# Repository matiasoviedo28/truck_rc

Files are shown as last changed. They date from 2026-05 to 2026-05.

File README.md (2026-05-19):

# RC Truck NeutronLab — ESP32 Control System

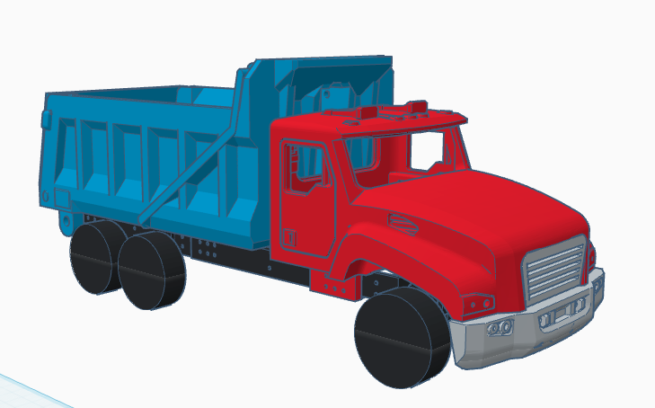
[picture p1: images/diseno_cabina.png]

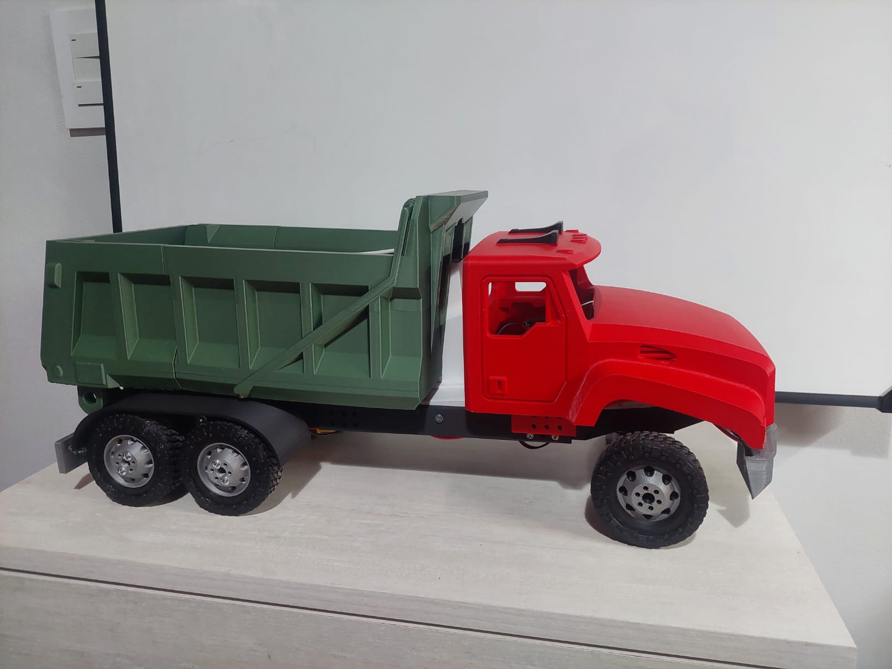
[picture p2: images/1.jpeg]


Sistema de control inalámbrico para camión RC con tolva volcadora basado en ESP32, con interfaz web embebida accesible desde cualquier celular sin necesidad de aplicación.

El proyecto reemplaza los radiocontroles tradicionales por un control vía WiFi (modo Access Point) servido directamente desde el ESP32, replicando el comportamiento de un camión real: cardán/toma de fuerza, bloqueos cruzados de seguridad, luces de freno con timer, balizas, indicadores de giro automáticos y failsafe por pérdida de conexión.

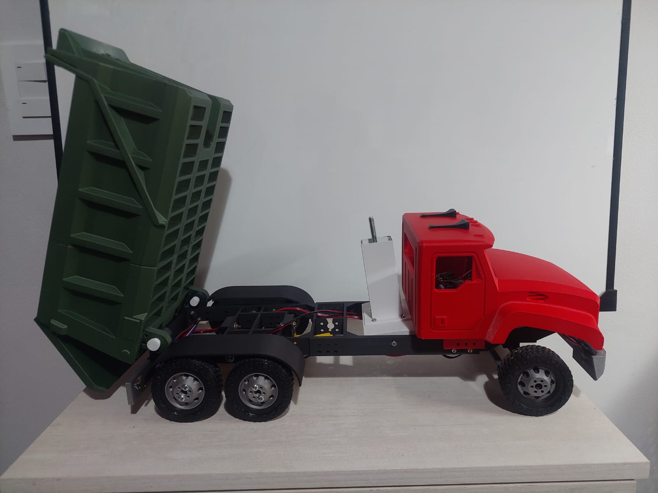
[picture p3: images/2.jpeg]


---

## Tabla de contenidos

- [Características principales](#características-principales)
- [Hardware utilizado](#hardware-utilizado)
- [Documentación](#documentación)
- [Estructura del proyecto](#estructura-del-proyecto)
- [Contribuciones](#contribuciones)
- [Licencia](#licencia)
- [Créditos](#créditos)

---

## Características principales

- **Control vía WiFi sin internet** — el ESP32 crea su propio Access Point, no requiere router externo.
- **Interfaz web embebida** — funciona en cualquier celular con navegador, sin instalar apps.
- **Volante táctil SVG** — control de dirección con gestos de rotación realistas.
- **Tolva con motor paso a paso** — controlada directamente desde el ESP32 con AccelStepper.
- **Cardán virtual** — simula la toma de fuerza de un camión real con bloqueos cruzados.
- **Sistema de luces realista** — bajas, freno con timer, reversa, giros automáticos y balizas.
- **Failsafe automático** — corta motores ante pérdida de conexión.
- **Indicador ONLINE/OFFLINE** en tiempo real.

---

## Hardware utilizado

| Componente | Modelo / Especificación |
|---|---|
| Microcontrolador | ESP32 DevKit V1 (30 pines) |
| Driver paso a paso | A4988 (con disipador) |
| Motor de tolva | NEMA17 |
| Motor de tracción | DC con driver PWM (puente H) |
| Servo de dirección | SG90 / MG90S (50 Hz, 500-2400 µs) |
| Alimentación motor | 12V (batería o fuente) |
| Alimentación lógica | 5V (del ESP32 o externa) |
| LEDs | Luces bajas, freno, reversa, giros izq/der |

---

## Documentación

| Archivo | Contenido |
|---|---|
| [`guia_armado.md`](guia_armado.md) | Paso a paso completo: impresión 3D, ensamble mecánico y eléctrico |
| [`conexiones.md`](conexiones.md) | Diagrama de conexiones, tabla de pines ESP32 y configuración del A4988 |
| [`interfaz_web.md`](interfaz_web.md) | Control WiFi, protocolo HTTP e interfaz visual |
| [`funciones.md`](funciones.md) | Funciones del camión y sistema de seguridad / failsafe |
| [`instalacion.md`](instalacion.md) | Requisitos, librerías y carga del firmware |

---

## Estructura del proyecto

```
.
├── truck_rc_neutronlab.ino   # Sketch principal del ESP32
├── README.md                 # Este archivo
├── guia_armado.md            # Paso a paso de construcción
├── conexiones.md             # Pines y diagrama eléctrico
├── interfaz_web.md           # Control WiFi e interfaz
├── funciones.md              # Funciones y failsafe
├── instalacion.md            # Carga del firmware
├── images/                   # Imágenes del proyecto
└── stl/                      # Archivos para impresión 3D
```

---

## Contribuciones

Las contribuciones son bienvenidas. Si querés agregar funcionalidades, corregir bugs o adaptar el proyecto a otros chasis, hacé un fork y mandá un pull request.

Ideas pendientes de implementación:
- Control de velocidad gradual (actualmente PWM fijo en 255).
- Conversión a WebSockets para reducir latencia.
- Modo de "pausa" para el truck con configuración persistente.
- Telemetría de batería.

---

## Licencia

Este proyecto está bajo licencia MIT — libre uso, modificación y distribución.

---

## Créditos

**Proyecto creado por:** Matías Oviedo
**Nick:** NeutronLab
**Contacto:** matiasalbertooviedogonzalez@gmail.com

---

> Si te sirvió el proyecto o te gustó la idea, no olvides dejar una estrella en el repositorio.

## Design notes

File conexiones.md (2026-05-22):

# Diagrama de conexiones y pines

## Diagrama general

```
                        ┌─────────────────┐
                        │   CELULAR       │
                        │   (Navegador)   │
                        └────────┬────────┘
                                 │ WiFi 2.4 GHz
                                 │ (AP del ESP32)
                                 │
                        ┌────────▼────────┐
                        │     ESP32       │
                        │   (Servidor     │
                        │     web AP)     │
                        └────────┬────────┘
                                 │
        ┌────────────┬───────────┼───────────┬──────────────┐
        │            │           │           │              │
   ┌────▼────┐  ┌────▼────┐ ┌────▼────┐ ┌────▼────┐  ┌──────▼──────┐
   │  Servo  │  │ Driver  │ │ Driver  │ │  LEDs   │  │   Driver    │
   │ Dirección│ │ Motor DC│ │  A4988  │ │ (luces) │  │   A4988     │
   │         │  │ (PWM)   │ │ NEMA17  │ │         │  │             │
   └─────────┘  └─────────┘ └─────────┘ └─────────┘  └─────────────┘
```

---

## Tabla de pines del ESP32

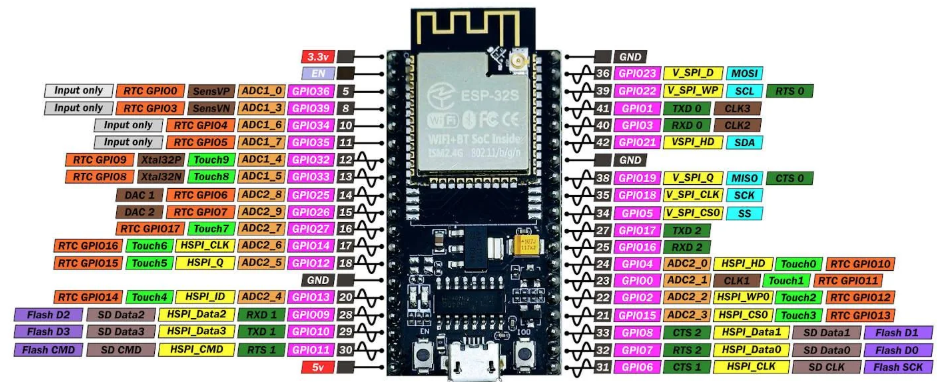
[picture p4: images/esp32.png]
ESP32


| GPIO | Función | Descripción |
|---|---|---|
| **2** | Servo dirección | PWM 50 Hz al servo (rango 500-2400 µs) |
| **4** | DIR (A4988) | Dirección del motor paso a paso de tolva |
| **12** | Motor A | PWM hacia adelante (motor de tracción) |
| **13** | Motor B | PWM hacia atrás / reversa |
| **14** | Luces bajas | Salida digital LED bajas |
| **25** | Giro izquierdo | Salida digital LED giro izq |
| **26** | Luz reversa | Salida digital LED reversa |
| **27** | Luz freno | Salida digital LED freno (timer 1500 ms) |
| **32** | STEP (A4988) | Pulsos al motor paso a paso de tolva |
| **33** | Giro derecho | Salida digital LED giro der |
| **5** | ENABLE (A4988) | Habilitación del driver — LOW = activo, HIGH = desactivado |

---

## Conexión del driver A4988

| Pin A4988 | Conectar a | Observación |
|---|---|---|
| VMOT | +12V | Alimentación del motor |
| GND (motor) | GND batería 12V | |
| VDD | +5V | Alimentación de lógica del driver |
| GND (lógica) | GND del ESP32 | **Crítico:** debe compartir GND con ESP32 |
| STEP | GPIO 32 | Pulsos de paso |
| DIR | GPIO 4 | Sentido de giro |
| ENABLE | GPIO 5 | Controlado por software — no conectar a GND |
| RESET | SLEEP | Puenteados entre sí |
| 1A, 1B, 2A, 2B | Bobinas NEMA17 | Identificar con multímetro en continuidad |

> ⚠️ **Importante:** Calibrar el **Vref** del A4988 antes de usarlo. Para NEMA17 típico (1.5A) debe estar entre 0.6V y 0.8V. Medir entre el potenciómetro y GND con el driver alimentado pero **sin el motor conectado**.

> ⚠️ **Nunca conectar o desconectar el motor con el driver alimentado** — destruye instantáneamente el A4988.

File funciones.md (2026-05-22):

# Funciones del camión y sistema de seguridad

## Funciones del camión

### Dirección

- Volante táctil con rotación de hasta ±360° (dos vueltas completas a cada lado).
- Mapeo proporcional al servo físico (rango 55° a 135°, centro en 95°).
- Vuelve al centro automáticamente al soltar.

### Tracción

- **Modo RÁPIDO:** un toque al acelerador y el truck queda avanzando hasta tocar FRENO.
- **Modo LENTO:** mantener presionado para avanzar, soltar para detener.
- Reversa con la misma lógica según modo.

### Tolva volcadora

- Motor NEMA17 controlado con AccelStepper (no bloqueante).
- Recorrido seguro: **9000 pasos** (con margen del límite físico real de 10000).
- Velocidad: 1000 pasos/s, aceleración 400 pasos/s².
- Botón se ilumina durante el movimiento y se apaga al terminar.
- Comportamiento "un toque": va sola hasta el tope, sin STOP intermedio.
- Posición de reposo al encender: **tolva abajo = 0 pasos**. Subir avanza hacia `PASOS_MAXIMOS`, bajar regresa a `0`.

#### Gestión de energía del driver (pin ENABLE)

El driver A4988 se controla mediante el pin **GPIO 5** (ENABLE), evitando que el motor consuma corriente innecesariamente cuando está quieto.

| Momento | Estado ENABLE | Efecto |
|---|---|---|
| Arranque del sistema | HIGH (inactivo) | Motor frío, sin consumo |
| Se recibe comando UP/DOWN | LOW (activo) + delay 2 ms | Driver despierta antes del primer pulso |
| Tolva llega al destino | HIGH (inactivo) | Corriente cortada al terminar |
| Failsafe por pérdida de WiFi | HIGH (inactivo) | Motor se detiene y se desenergiza |

> **Por qué importa:** un NEMA17 parado pero energizado puede alcanzar 50–70 °C en pocos minutos y drenar la batería continuamente. Con el control de ENABLE el motor solo consume durante el movimiento efectivo.

### Sistema de luces

- **Luces bajas:** toggle manual.
- **Luz de freno:** se enciende automáticamente al transicionar de movimiento a detenido, durante **1500 ms** y se apaga sola.
- **Luz de reversa:** activa mientras el truck va en reversa.
- **Giros automáticos:** parpadean en el lado correspondiente cuando el volante supera ±45°.
- **Balizas (4 intermitentes):** toggle manual, parpadeo a 500 ms.

### Cardán (toma de fuerza simulada)

Replica el comportamiento real de un camión: la tolva solo puede operar con el cardán acoplado.

**Bloqueos cruzados:**
- El cardán solo se puede acoplar/desacoplar con el motor detenido.
- Con el cardán acoplado, el acelerador y reversa quedan bloqueados.
- La tolva solo responde si: cardán acoplado + motor detenido + conexión OK.

---

## Sistema de seguridad y failsafe

El sistema tiene múltiples capas de seguridad pensadas para un control inalámbrico.

### Detección de desconexión

- **Frontend (celular):** detecta OFFLINE si no recibe respuesta del ESP32 en **500 ms**.
- **Backend (ESP32):** activa el failsafe si no recibe comandos del frontend en **1000 ms**.

### Acciones de failsafe

Cuando el ESP32 detecta pérdida de conexión:

| Componente | Acción |
|---|---|
| Motor de tracción | **Apagado inmediato** (PWM a 0) |
| Tolva (paso a paso) | **Detención** con `stepper.stop()` + driver desenergizado (ENABLE = HIGH) |
| Servo de dirección | **Queda quieto** en su última posición |
| Luces bajas | Apagadas |
| Balizas | Mantienen parpadeo (señal visual de vehículo abandonado) |

### Defensa en profundidad

Los bloqueos cruzados (cardán ↔ motor, motor ↔ tolva, cardán ↔ tolva) se validan **tanto en el frontend como en el backend**. Aunque el frontend bloquea visualmente los botones inválidos, el ESP32 también los ignora si llegan por algún glitch o manipulación del request.

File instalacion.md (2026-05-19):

# Instalación del firmware

## Requisitos

- Arduino IDE 1.8+ o 2.x
- Plataforma ESP32 instalada en el IDE ([guía oficial](https://docs.espressif.com/projects/arduino-esp32/en/latest/installing.html))

## Librerías necesarias

Instalar desde el **Library Manager** del IDE:

- **AccelStepper** (Mike McCauley) — control del NEMA17
- **ESP32Servo** — control del servo
- `WiFi.h` y `WebServer.h` — incluidas en la plataforma ESP32

## Pasos

1. Clonar el repositorio:
   ```bash
   git clone https://github.com/TU_USUARIO/rc-truck-neutronlab.git
   ```
2. Abrir el archivo `.ino` con Arduino IDE.
3. Seleccionar la placa: **ESP32 Dev Module**.
4. Conectar el ESP32 por USB y elegir el puerto correspondiente.
5. Compilar y subir.
6. Abrir el Serial Monitor a **115200 baudios** para ver la IP del AP al iniciar.

## Prueba inicial recomendada

Antes de conectar todo el hardware, sugiero probar en este orden:

1. ✅ Subir el sketch al ESP32 sin nada conectado.
2. ✅ Conectarse al WiFi `Camion-RC-NeutronLab` desde el celular.
3. ✅ Acceder a `192.168.4.1` y verificar que la interfaz cargue.
4. ✅ Conectar el servo y las luces.
5. ✅ Conectar el motor de tracción.
6. ✅ **Último paso:** conectar el driver A4988 + NEMA17 (con Vref ya calibrado).

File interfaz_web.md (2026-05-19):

# Control WiFi e interfaz web

## Arquitectura

El ESP32 funciona como **Access Point WiFi independiente**. No se conecta a ninguna red externa: crea su propia red a la que el celular se conecta directamente. Esto significa:

- ✅ Funciona en cualquier lugar sin necesidad de WiFi externo
- ✅ Latencia mínima (sin pasar por router)
- ✅ Sin dependencia de internet
- ❌ El celular no tendrá acceso a internet mientras esté conectado al truck

---

## Conexión desde el celular

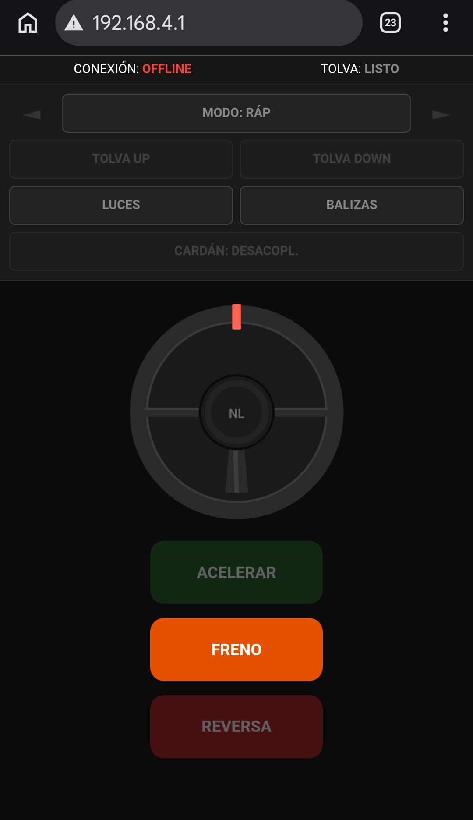
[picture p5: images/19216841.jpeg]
Conexión WiFi


1. **Red WiFi:** `Camion-RC-NeutronLab`
2. **Contraseña:** `12345678`
3. **Abrir navegador en:** `http://192.168.4.1`

Ambos valores se pueden modificar al inicio del sketch:

```cpp
const char* ssid     = "Camion-RC-NeutronLab";
const char* password = "12345678";
```

---

## Protocolo de comunicación

El frontend hace **polling HTTP cada 100 ms** al endpoint `/c` con los siguientes parámetros:

| Parámetro | Tipo | Valores | Descripción |
|---|---|---|---|
| `m` | int | 0, 1, 2 | Estado del motor: 0=stop, 1=adelante, 2=reversa |
| `d` | int | -360 a 360 | Ángulo del volante virtual |
| `l` | int | 0, 1 | Luces bajas |
| `h` | int | 0, 1 | Balizas (4 intermitentes) |
| `c` | int | 0, 1 | Cardán acoplado |
| `t` | char | U, D, espacio | Comando de tolva: Up, Down, sin acción |

**Ejemplo de request:**
```
GET /c?m=1&d=45&l=1&h=0&c=0&t=U
```

**Respuesta del ESP32:** estado actual de la tolva (`LISTO`, `SUBIENDO` o `BAJANDO`) en texto plano.

---

## Interfaz visual

La interfaz está optimizada para uso vertical en celulares y cuenta con:

- **Header con chips de estado:** CONEXIÓN (ONLINE/OFFLINE) y TOLVA (estado actual).
- **Indicadores de giro:** flechas ◄ ► que parpadean en naranja según ángulo del volante o si las balizas están activas.
- **Volante SVG estilo camión clásico** con marcador rojo central y 3 rayos.
- **Triggers verticales:** ACELERAR (verde), FRENO (naranja), REVERSA (rojo).
- **Controles de tolva:** TOLVA UP / TOLVA DOWN con bloqueos automáticos.
- **Botón CARDÁN** con feedback de estado (ACOPLADO / DESACOPL.).
- **Modo de manejo:** RÁPIDO (toque y mantiene) o LENTO (mantener presionado).

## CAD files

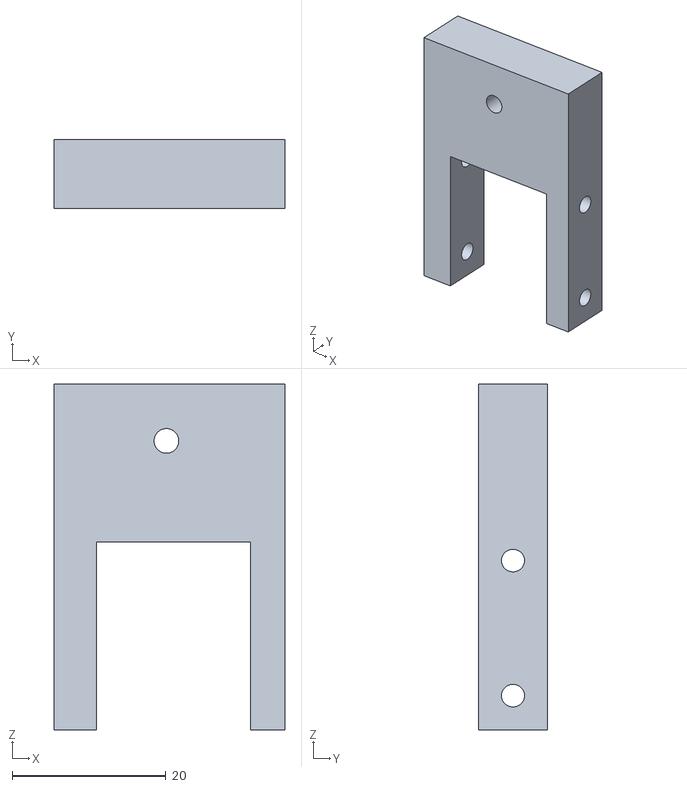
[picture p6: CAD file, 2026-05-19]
stl/SUPORT_MOTOR.stl
30.0 x 9.00 x 45.0

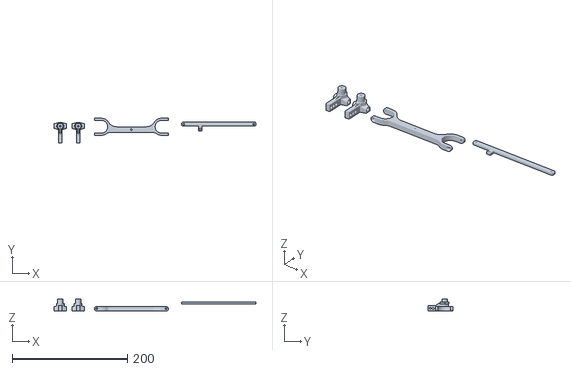
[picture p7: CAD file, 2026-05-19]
stl/DIRECCION_ARTICULADA.stl
350.1 x 42.9 x 21.0

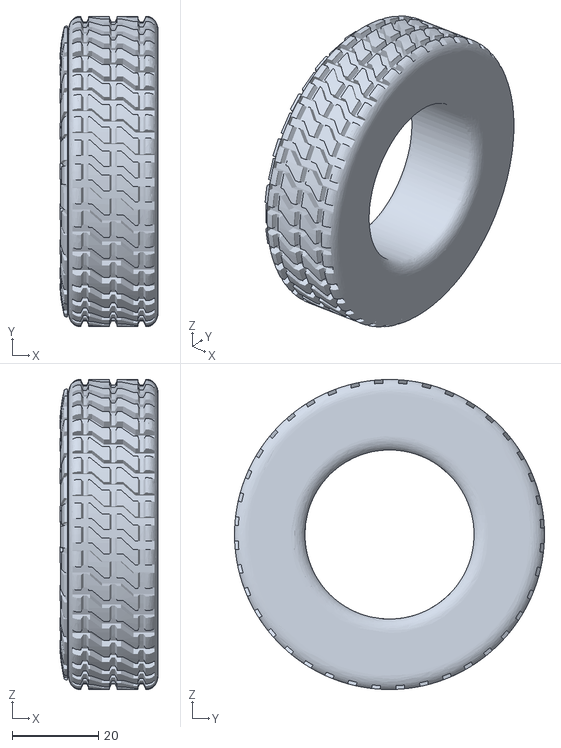
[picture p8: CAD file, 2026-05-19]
stl/NEUMATICO.stl
22.8 x 72.0 x 72.0

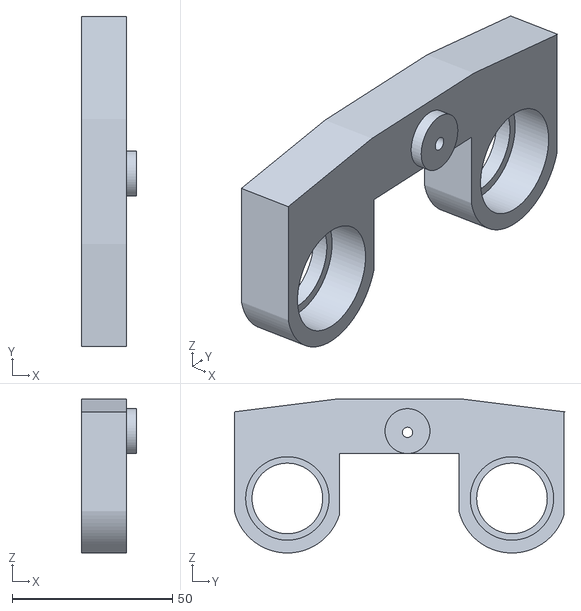
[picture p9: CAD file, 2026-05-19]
stl/MASAS.stl
17.0 x 103.0 x 48.0

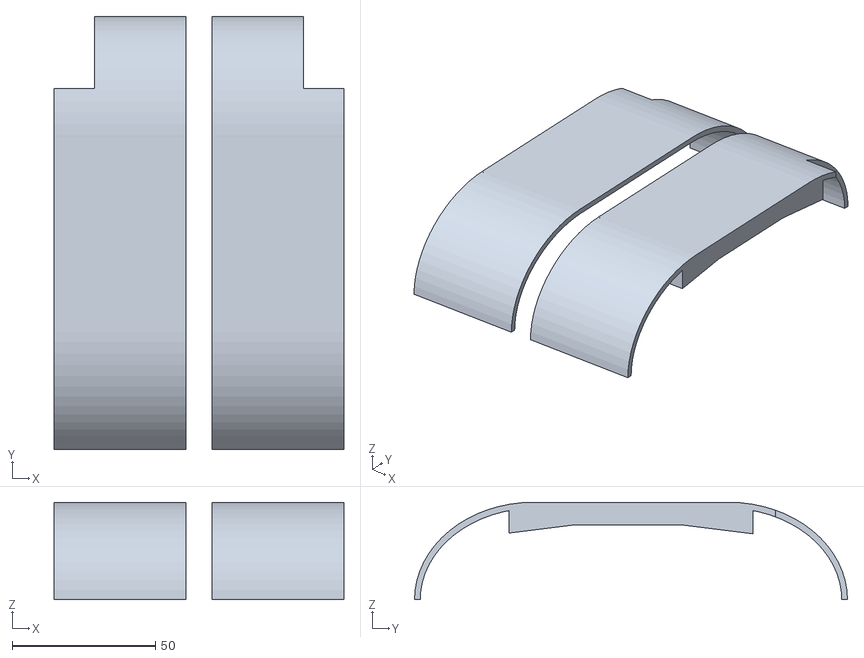
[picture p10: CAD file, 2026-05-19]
stl/GUARDABARROS_TRA.stl
101.0 x 151.0 x 34.0

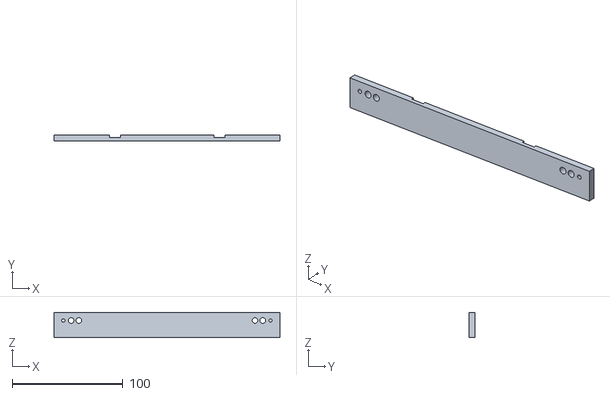
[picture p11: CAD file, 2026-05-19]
stl/PARACHOQUES_TRA.stl
204.0 x 5.00 x 23.0

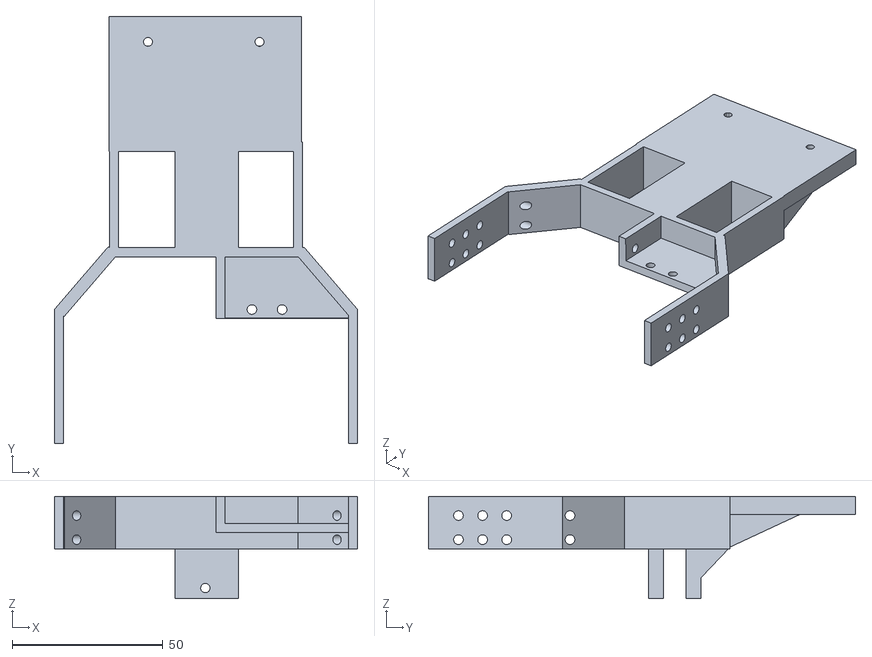
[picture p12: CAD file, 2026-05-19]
stl/CHASIS_1.stl
100.5 x 141.8 x 34.0

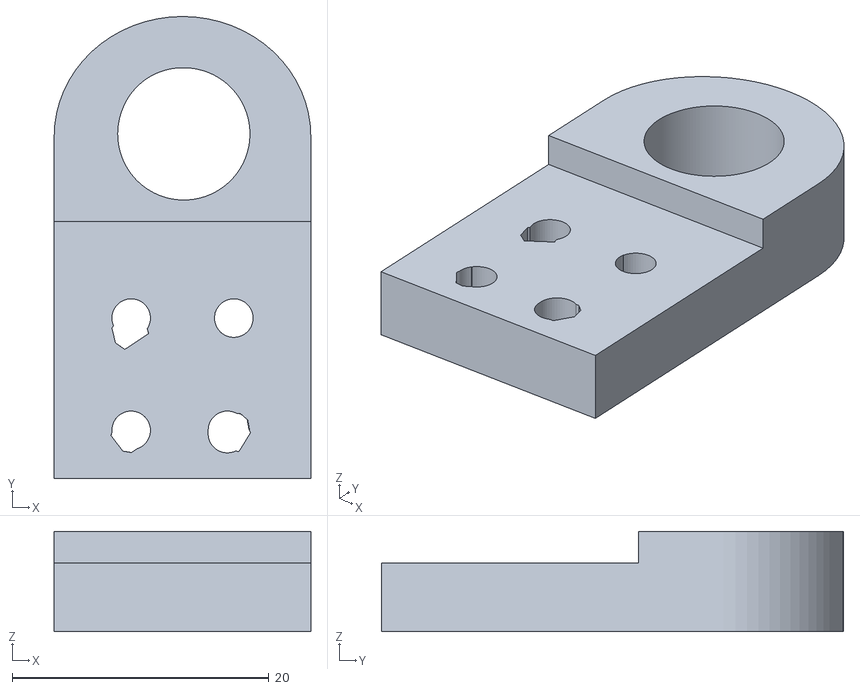
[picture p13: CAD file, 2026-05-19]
stl/BISAGRA_TOLVA.stl
20.0 x 36.0 x 7.80

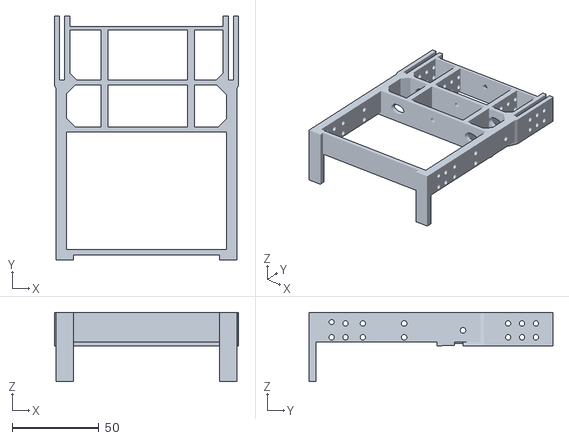
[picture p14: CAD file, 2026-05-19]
stl/CHASIS_3.stl
106.5 x 141.0 x 40.0

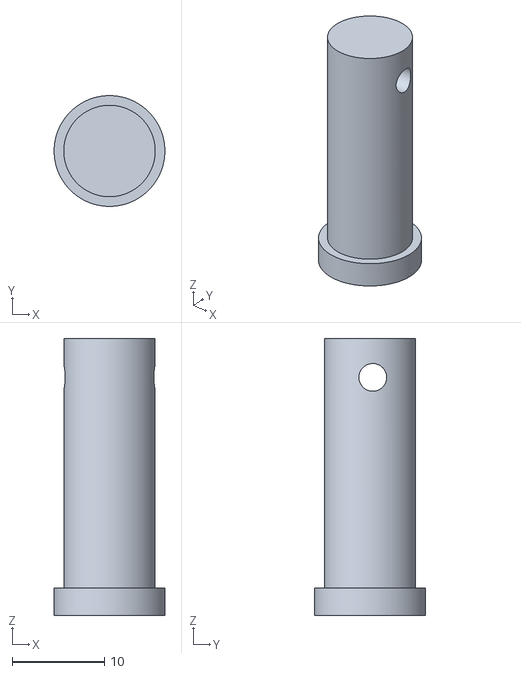
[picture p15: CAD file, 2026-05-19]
stl/PERNO_TOLVA.stl
12.0 x 12.0 x 30.0

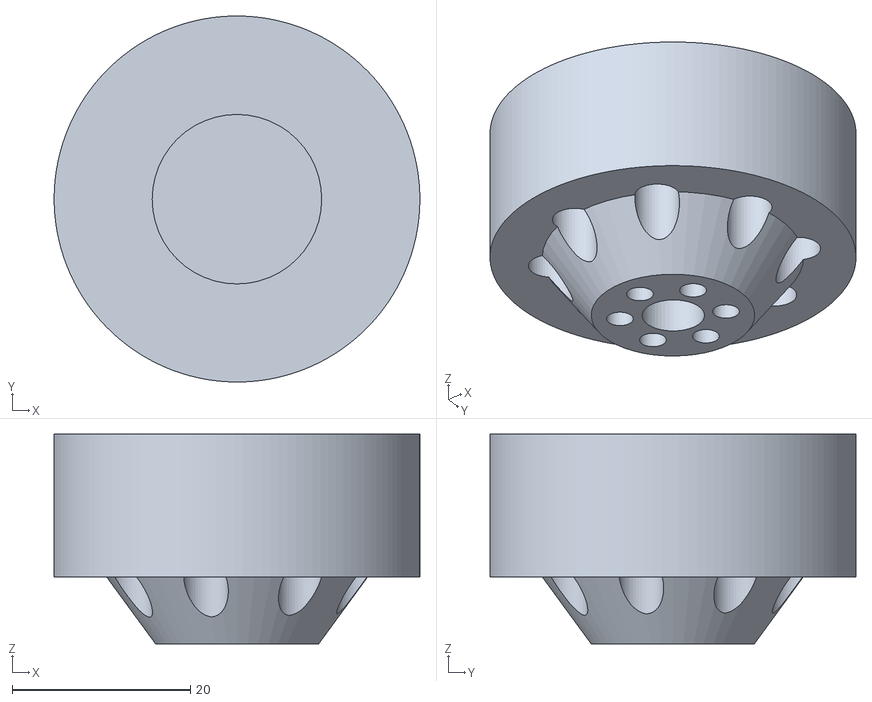
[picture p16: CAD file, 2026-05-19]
stl/LLANTA_DEL.stl
41.0 x 41.0 x 23.5

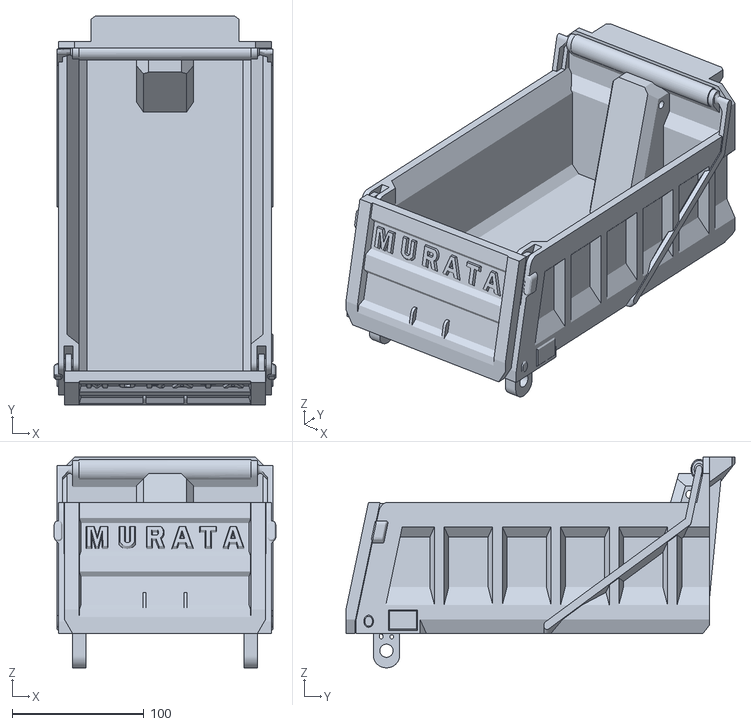
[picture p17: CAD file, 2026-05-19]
stl/CAJA_TOLVA.stl
168.5 x 295.8 x 160.2

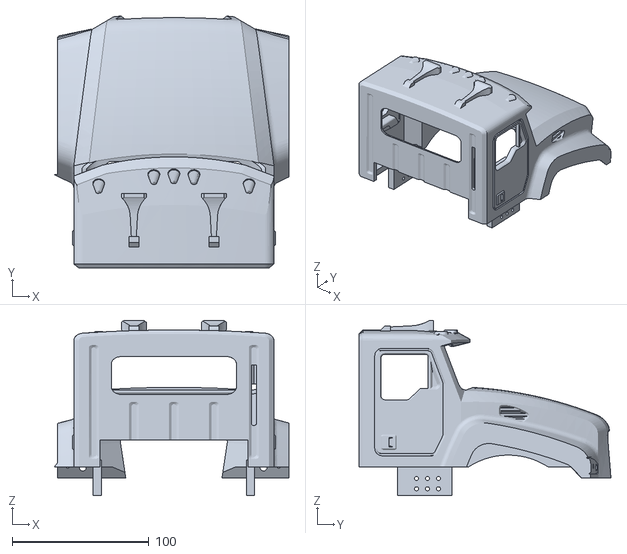
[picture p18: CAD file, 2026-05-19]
stl/CABINA.stl
171.5 x 184.0 x 128.0

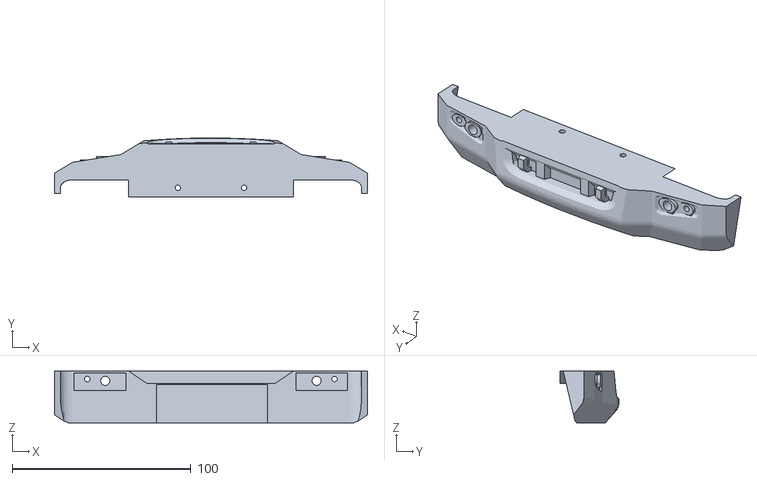
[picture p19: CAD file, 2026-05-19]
stl/PARACHOQUES_DEL.stl
175.0 x 33.0 x 29.0

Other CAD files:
stl/LLANTA_TRA.stl
stl/RADIADOR.stl
stl/EJE.stl
stl/CHASIS_2.stl

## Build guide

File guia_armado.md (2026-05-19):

# Guía de armado — RC Truck NeutronLab

Truck terminado

Esta guía cubre todo el proceso de construcción del camión RC: desde imprimir las piezas hasta la puesta en marcha. Seguí el orden recomendado para evitar tener que desarmar cosas que ya ensamblaste.

---

## Tabla de contenidos

- [Materiales y herramientas necesarias](#materiales-y-herramientas-necesarias)
- [Paso 1 — Impresión 3D](#paso-1--impresión-3d)
- [Paso 2 — Armado del chasis](#paso-2--armado-del-chasis)
- [Paso 3 — Ejes y ruedas](#paso-3--ejes-y-ruedas)
- [Paso 4 — Sistema de dirección](#paso-4--sistema-de-dirección)
- [Paso 5 — Motor de tracción](#paso-5--motor-de-tracción)
- [Paso 6 — Electrónica y cableado](#paso-6--electrónica-y-cableado)
- [Paso 7 — Tolva volcadora](#paso-7--tolva-volcadora)
- [Paso 8 — Carrocería y detalles](#paso-8--carrocería-y-detalles)
- [Paso 9 — Prueba final](#paso-9--prueba-final)

---

## Materiales y herramientas necesarias

### Herramientas

- Impresora 3D (usé Bambu Lab A1)
- Destornillador Phillips y plano
- Llave allen (set métrico)
- Multímetro digital
- Soldador de estaño + estaño
- Termocontraíble o cinta aisladora
- Pinza de punta fina

### Tornillería y extras

> _(completar con los tornillos exactos que uses: M2, M3, etc., largo y cantidad)_

| Ítem | Cantidad |
|---|---|
| Tornillos M3 x 10mm | ___ |
| Tornillos M3 x 20mm | ___ |
| Tornillos M2 x 8mm | ___ |
| Tuercas M3 | ___ |
| Varilla roscada (eje tolva) | ___ |
| Cables dupont / silicona | c/n |

---

## Paso 1 — Impresión 3D

Imprimí todas las piezas antes de empezar el armado. Así tenés todo listo y evitás interrupciones.

### Configuración utilizada

| Parámetro | Valor |
|---|---|
| Impresora | Bambu Lab A1 |
| Boquilla | 0.4 mm |
| Altura de capa | 0.2 mm |
| Paredes | 3–4 (ver tabla) |
| Relleno | 20% |
| Material | PLA o PETG |

### Lista de STLs

| Archivo STL | Cantidad | Paredes | Observaciones |
|---|---|---|---|
| `CHASIS_1.stl` | 1 | 4 | Pieza estructural, imprimí con boca abajo si tiene voladizos |
| `CHASIS_2.stl` | 1 | 4 | |
| `CHASIS_3.stl` | 1 | 4 | |
| `EJE.stl` | ___ | 4 | Pieza de carga, máximo relleno recomendado |
| `MASAS.stl` | ___ | 4 | |
| `LLANTA_DEL.stl` | 2 | 3 | |
| `LLANTA_TRA.stl` | 4 | 3 | |
| `NEUMATICO.stl` | 6 | 3 | Imprimir en TPU si es posible, sino PLA flexible |
| `DIRECCION_ARTICULADA.stl` | 1 | 4 | |
| `SUPORT_MOTOR.stl` | 1 | 4 | |
| `CABINA.stl` | 1 | 3 | Pieza estética |
| `RADIADOR.stl` | 1 | 3 | |
| `PARACHOQUES_DEL.stl` | 1 | 3 | |
| `PARACHOQUES_TRA.stl` | 1 | 3 | |
| `GUARDABARROS_TRA.stl` | 2 | 3 | |
| `CAJA_TOLVA.stl` | 1 | 3–4 | |
| `BISAGRA_TOLVA.stl` | ___ | 4 | |
| `PERNO_TOLVA.stl` | ___ | 4 | |

> **Tip:** Las piezas del chasis conviene imprimirlas primero y verificar que encajan antes de imprimir la carrocería.

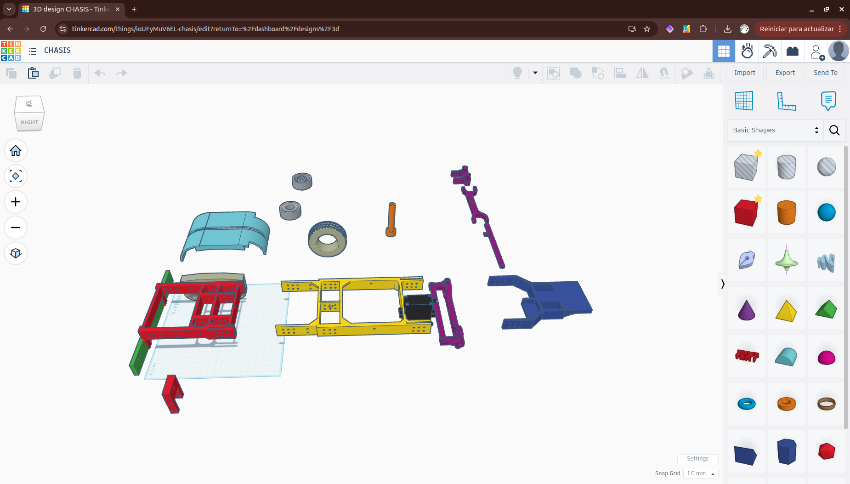
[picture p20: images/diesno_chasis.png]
Diseño del chasis


---

## Paso 2 — Armado del chasis

> 📷 _Foto: chasis armado sin electrónica_

El chasis se divide en 3 partes (`CHASIS_1`, `CHASIS_2`, `CHASIS_3`) que se unen entre sí con tornillos.

**Pasos:**

1. Unir `CHASIS_1` con `CHASIS_2` — alinear los orificios y fijar con tornillos ___(especificar)___.
2. Unir `CHASIS_3` al conjunto anterior.
3. Verificar que el chasis quede rígido y sin flexión lateral.

> _(agregar foto del chasis ensamblado)_

---

## Paso 3 — Ejes y ruedas

> 📷 _Foto: ruedas traseras y eje montados_

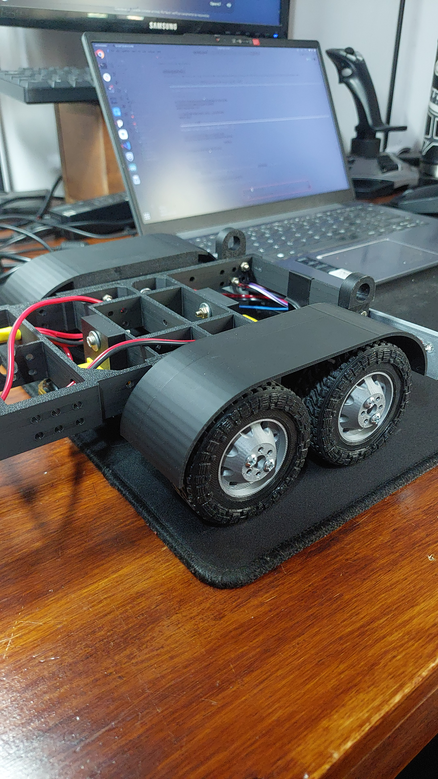
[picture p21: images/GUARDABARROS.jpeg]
Ejes traseros en construcción


**Ensamble de ruedas:**

1. Montar las `MASAS` en el eje.
2. Colocar la `LLANTA_TRA` sobre la masa y fijar con tornillo central.
3. Instalar el `NEUMATICO` sobre la llanta (con un poco de calor si ajusta muy justo en PLA).
4. Repetir para las 4 ruedas traseras y las 2 delanteras (`LLANTA_DEL`).

**Montaje de ejes al chasis:**

1. Insertar el `EJE` en los soportes del chasis.
2. ___(describir cómo queda retenido — tuerca, clip, etc.)___

> _(agregar foto del eje instalado en el chasis)_

---

## Paso 4 — Sistema de dirección

> 📷 _Foto: servo y dirección articulada instalados_

1. Montar la `DIRECCION_ARTICULADA` en el chasis delantero.
2. Insertar el servo SG90/MG90S en su cavidad.
3. Conectar el brazo del servo al mecanismo de dirección.
4. Verificar que el rango de giro no toca topes mecánicos antes de energizar — el código mapea 55° a 135° (centro 95°).

> _(agregar foto del servo instalado)_

---

## Paso 5 — Motor de tracción

> 📷 _Foto: motor DC montado en el soporte_

1. Colocar el motor DC en el `SUPORT_MOTOR`.
2. Fijar el soporte al chasis en la posición ___(especificar)___.
3. Conectar la transmisión al eje trasero ___(describir si hay engranaje, correa, etc.)___.
4. Verificar que el eje gira libre sin fricción excesiva.

> _(agregar foto del motor instalado)_

---

## Paso 6 — Electrónica y cableado

> 📷 _Foto: chasis con toda la electrónica antes de cerrar_

Tolva levantada — electrónica visible

### Componentes a instalar

- ESP32 DevKit V1 (30 pines)
- Driver A4988 + disipador
- Puente H (motor DC)
- LEDs (bajas, freno, reversa, giros)
- Servo SG90/MG90S (ya instalado en paso 4)

### Diagrama de pines

ESP32 conexiones

| GPIO | Función |
|---|---|
| 2 | Servo dirección |
| 4 | DIR (A4988 tolva) |
| 12 | Motor A (adelante) |
| 13 | Motor B (reversa) |
| 14 | Luces bajas |
| 25 | Giro izquierdo |
| 26 | Luz reversa |
| 27 | Luz freno |
| 32 | STEP (A4988 tolva) |
| 33 | Giro derecho |

### Calibración del A4988 (Vref)

> ⚠️ **Hacer esto antes de conectar el NEMA17.**

1. Alimentar el driver (12V en VMOT, 5V en VDD) **sin el motor conectado**.
2. Medir entre el potenciómetro del A4988 y GND.
3. Ajustar hasta obtener entre **0.6V y 0.8V** para un NEMA17 de 1.5A.

> ⚠️ **Nunca enchufar o desenchufar el motor con el driver alimentado.**

### Orden de conexión recomendado

1. ESP32 solo (verificar que el sketch carga y el AP WiFi aparece).
2. Servo + LEDs.
3. Puente H + motor DC.
4. A4988 + NEMA17 (con Vref ya calibrado).

> _(agregar foto del cableado terminado)_

---

## Paso 7 — Tolva volcadora

> 📷 _Foto: tolva armada y bisagra instalada_

1. Armar la `CAJA_TOLVA` — ___(describir si tiene partes que se pegan o atornillan)___.
2. Instalar las `BISAGRA_TOLVA` en la parte trasera del chasis.
3. Apoyar la caja de la tolva sobre las bisagras y fijar con el `PERNO_TOLVA`.
4. Montar el NEMA17 en su soporte — verificar que el mecanismo de elevación mueve la tolva sin trabar.
5. Conectar el NEMA17 al A4988 (identificar bobinas con multímetro en modo continuidad: pares que tienen continuidad entre sí son la misma bobina).

> **Recorrido del motor:** 9000 pasos configurados en el código (límite físico real ~10000).

> _(agregar foto de la tolva levantada con el mecanismo visible)_

---

## Paso 8 — Carrocería y detalles

> 📷 _Foto: carrocería siendo colocada_

Diseño de cabina

1. Colocar el `RADIADOR` en la parte delantera del chasis.
2. Encajar la `CABINA` sobre el chasis — ___(describir cómo fija: tornillos, clips, etc.)___.
3. Montar `PARACHOQUES_DEL` adelante y `PARACHOQUES_TRA` atrás.
4. Colocar los `GUARDABARROS_TRA` sobre las ruedas traseras.
5. Pasar los cables de LEDs delanteros y traseros por dentro de la carrocería.

> _(agregar foto de la carrocería completa antes de cerrar)_

---

## Paso 9 — Prueba final

Truck terminado en acción

### Checklist de prueba

- [ ] El ESP32 crea el AP WiFi `Camion-RC-NeutronLab`
- [ ] Desde el celular se accede a `http://192.168.4.1`
- [ ] La interfaz muestra ONLINE
- [ ] El servo responde al volante virtual
- [ ] El motor DC avanza y retrocede
- [ ] Las luces bajas encienden y apagan
- [ ] Los giros parpadean al girar el volante más de 45°
- [ ] La luz de freno enciende al detener el truck (1500 ms)
- [ ] La tolva sube y baja (solo con cardán acoplado + motor detenido)
- [ ] El failsafe corta los motores al desconectar el WiFi

### Vista final

Truck terminado — lateral

Truck con tolva levantada

---

> Si tenés dudas o encontraste algo que mejorar, abrí un issue en el repositorio o mandame un mensaje. ¡Que ruede!

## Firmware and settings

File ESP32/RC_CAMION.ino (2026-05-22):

#include <WiFi.h>
#include <WebServer.h>
#include <ESP32Servo.h>
#include <AccelStepper.h>

// V.3.1 - 22/06/2026
// Matias Oviedo - NeutronLab
// https://github.com/matiasoviedo28/truck_rc

// --- CONFIGURACIÓN DE HARDWARE ---
const int pinServo    = 2;
const int pinMotorA   = 12;
const int pinMotorB   = 13;
const int pinBajas    = 14;
const int pinFreno    = 27;
const int pinReversa  = 26;
const int pinGiroIzq  = 25;
const int pinGiroDer  = 33;
const int pinStep     = 32;
const int pinDir      = 4;
const int pinEnable   = 5;

// --- DIRECCIÓN (SERVO) ---
const int OFFSET_RECTO = 95;
const int MAX_IZQ      = 55;
const int MAX_DER      = 135;

// --- TOLVA (STEPPER) ---
const long PASOS_MAXIMOS = 9000;
const float STEPPER_VMAX = 1000.0;
const float STEPPER_ACEL = 400.0;

// --- TIMERS ---
const unsigned long BRAKE_DURATION_MS   = 1500;
const unsigned long FAILSAFE_TIMEOUT_MS = 1000;
const unsigned long BLINK_PERIOD_MS     = 500;

// --- WIFI ---
const char* ssid     = "Camion-RC-NeutronLab";
const char* password = "12345678";

WebServer server(80);
Servo direccion;
AccelStepper stepper(AccelStepper::DRIVER, pinStep, pinDir);

// --- ESTADO ---
int   motorState     = 0;     // 0=stop, 1=adelante, 2=reversa
float d_visual       = 0;     // -360..360
bool  lowLights      = false;
bool  hazard         = false;
bool  cardanAcoplado = false;

// --- TOLVA ---
enum TolvaEstado { T_LISTO, T_SUBIENDO, T_BAJANDO };
TolvaEstado tolvaEstado = T_LISTO;

// --- TIMERS DE ESTADO ---
unsigned long lastCommandTime = 0;
unsigned long brakeStartTime  = 0;
unsigned long lastBlink       = 0;
bool blinkState        = false;
bool brakeActive       = false;
int  lastMotorState    = 0;
bool failsafeActive    = false;

// ============================================================
// HTML EMBEBIDO
// ============================================================
const char html[] PROGMEM = R"rawliteral(
<!DOCTYPE html>
<html lang="es">
<head>
<meta charset="UTF-8">
<title>RC Truck Pro</title>
<meta name="viewport" content="width=device-width, initial-scale=1.0, user-scalable=no">
<style>
  body { margin: 0; background: #0b0b0b; color: white; font-family: sans-serif; overflow: hidden; touch-action: none; user-select: none; -webkit-user-select: none; }
  .status-bar { width: 100%; padding: 6px 8px; background: #151515; display: flex; justify-content: space-around; font-size: 11px; border-bottom: 1px solid #222; box-sizing: border-box; }
  .status-bar b { font-weight: bold; }
  .header-controls { background: #1a1a1a; border-bottom: 1px solid #333; padding: 8px; }
  .row { display: flex; gap: 6px; margin-bottom: 6px; align-items: center; }
  .row:last-child { margin-bottom: 0; }
  .btn { flex: 1; height: 34px; border-radius: 5px; border: 1px solid #444; background: #222; color: #888; font-size: 11px; font-weight: bold; }
  .arrow { width: 40px; height: 34px; display: flex; align-items: center; justify-content: center; font-size: 22px; color: #333; font-weight: bold; }
  .locked { opacity: 0.35; pointer-events: none; }
  .main-container { display: flex; flex-direction: column; align-items: center; padding: 14px 0; gap: 12px; }
  .wheel-container { width: 200px; height: 200px; }
  .wheel-svg { width: 100%; height: 100%; touch-action: none; }
  .trigger { width: 150px; height: 55px; font-size: 14px; font-weight: bold; border-radius: 12px; border: none; color: white; }
  .accel { background: #1b5e20; } .brake { background: #e65100; } .reverse { background: #b71c1c; }
  .pressed { filter: brightness(1.8); transform: scale(0.97); }
</style>
</head>
<body>

<div class="status-bar">
  <span>CONEXIÓN: <b id="connStatus" style="color:#2ecc71">ONLINE</b></span>
  <span>TOLVA: <b id="tolvaStatus" style="color:#888">LISTO</b></span>
</div>

<div class="header-controls">
  <div class="row">
    <div id="turnLeft" class="arrow">&#9668;</div>
    <button class="btn" id="swDrive">MODO: RÁP</button>
    <div id="turnRight" class="arrow">&#9658;</div>
  </div>
  <div class="row">
    <button class="btn" id="btnUp">TOLVA UP</button>
    <button class="btn" id="btnDown">TOLVA DOWN</button>
  </div>
  <div class="row">
    <button class="btn" id="lowBtn">LUCES</button>
    <button class="btn" id="hazardBtn">BALIZAS</button>
  </div>
  <div class="row">
    <button class="btn" id="cardanBtn">CARDÁN: DESACOPL.</button>
  </div>
</div>

<div class="main-container">
  <div class="wheel-container">
    <svg id="wheel" class="wheel-svg" viewBox="0 0 200 200">
      <circle cx="100" cy="100" r="92" fill="#1a1a1a" stroke="#0a0a0a" stroke-width="3"/>
      <circle cx="100" cy="100" r="86" fill="none" stroke="#2a2a2a" stroke-width="14"/>
      <circle cx="100" cy="100" r="78" fill="none" stroke="#3a3a3a" stroke-width="2"/>
      <rect x="20" y="96" width="160" height="8" fill="#2a2a2a"/>
      <rect x="20" y="96" width="160" height="2" fill="#3d3d3d"/>
      <polygon points="96,100 104,100 110,170 90,170" fill="#2a2a2a"/>
      <polygon points="96,100 100,100 102,170 98,170" fill="#3d3d3d"/>
      <circle cx="100" cy="100" r="32" fill="#1a1a1a" stroke="#0a0a0a" stroke-width="2"/>
      <circle cx="100" cy="100" r="28" fill="#222"/>
      <circle cx="100" cy="100" r="22" fill="#1a1a1a"/>
      <text x="100" y="105" text-anchor="middle" fill="#666" font-family="sans-serif" font-size="11" font-weight="bold">NL</text>
      <rect x="96" y="6" width="8" height="22" fill="#f44336" rx="1"/>
      <rect x="97" y="6" width="6" height="22" fill="#ff6659" rx="1"/>
    </svg>
  </div>
  <button class="trigger accel"   id="btnAccel">ACELERAR</button>
  <button class="trigger brake"   id="btnBrake">FRENO</button>
  <button class="trigger reverse" id="btnRev">REVERSA</button>
</div>

<script>
const wheel = document.getElementById("wheel");
const turnLeft = document.getElementById("turnLeft");
const turnRight = document.getElementById("turnRight");
const hazardBtn = document.getElementById("hazardBtn");
const lowBtn = document.getElementById("lowBtn");
const swDrive = document.getElementById("swDrive");
const cardanBtn = document.getElementById("cardanBtn");
const btnAccel = document.getElementById("btnAccel");
const btnRev = document.getElementById("btnRev");
const btnBrake = document.getElementById("btnBrake");
const btnUp = document.getElementById("btnUp");
const btnDown = document.getElementById("btnDown");
const connStatus = document.getElementById("connStatus");
const tolvaStatus = document.getElementById("tolvaStatus");

const ORANGE="#ff9800", ORANGE_BORDER="#ffb74d", ORANGE_BG="rgba(255,152,0,0.15)";
const GREEN="#2ecc71", RED="#f44336";
const OFF_TEXT="#888", OFF_BG="#222", OFF_BORDER="#444", ARROW_OFF="#333";

let curAng=0, tarAng=0, lastAng=0, isTouchWheel=false;
let hazardOn=false, lowOn=false, driveFast=true, cardanOn=false;
let motorSt=0, tolvaMoving=false, isOnline=true;
let blinkState=false, tolvaCmd=' ';
let lastOkTime = Date.now();

setInterval(()=>{ blinkState=!blinkState; updateBlinkVisuals(); }, 500);

function setBtnStyle(btn,active,bg,col,bd){
  if(active){ btn.style.background=bg; btn.style.color=col; btn.style.borderColor=bd; }
  else { btn.style.background=OFF_BG; btn.style.color=OFF_TEXT; btn.style.borderColor=OFF_BORDER; }
}
function setLock(btn,locked){ btn.classList.toggle("locked", locked); }

function updateBlinkVisuals(){
  const tL = curAng < -45, tR = curAng > 45;
  const lA = (hazardOn||tL) && isOnline;
  const rA = (hazardOn||tR) && isOnline;
  turnLeft.style.color  = (lA && blinkState) ? ORANGE : ARROW_OFF;
  turnRight.style.color = (rA && blinkState) ? ORANGE : ARROW_OFF;
  if(hazardOn){
    if(blinkState){ hazardBtn.style.background=ORANGE; hazardBtn.style.color="white"; hazardBtn.style.borderColor=ORANGE_BORDER; }
    else { hazardBtn.style.background=ORANGE_BG; hazardBtn.style.color=ORANGE; hazardBtn.style.borderColor=ORANGE_BORDER; }
  }
}

function updateLocks(){
  const stopped = motorSt===0;
  const accelOk = !cardanOn && isOnline;
  setLock(btnAccel, !accelOk);
  setLock(btnRev,   !accelOk);
  setLock(cardanBtn, !(stopped && isOnline));
  const tolvaOk = cardanOn && stopped && !tolvaMoving && isOnline;
  setLock(btnUp,   !tolvaOk);
  setLock(btnDown, !tolvaOk);
}

function getAngle(t){
  const r = wheel.getBoundingClientRect();
  return Math.atan2(t.clientY-(r.top+r.height/2), t.clientX-(r.left+r.width/2))*180/Math.PI;
}
wheel.addEventListener("touchstart",e=>{isTouchWheel=true;lastAng=getAngle(e.touches[0]);},{passive:true});
wheel.addEventListener("touchmove",e=>{
  e.preventDefault();
  const n=getAngle(e.touches[0]); let d=n-lastAng;
  if(d>180)d-=360; if(d<-180)d+=360;
  tarAng=Math.max(-360,Math.min(360,tarAng+d)); lastAng=n;
},{passive:false});
wheel.addEventListener("touchend",()=>{isTouchWheel=false;});

function setMotor(val,btn){
  if(cardanOn && val!==0) return;
  if(!isOnline && val!==0) return;
  motorSt = val;
  [btnAccel,btnRev,btnBrake].forEach(b=>b.classList.remove("pressed"));
  if(btn) btn.classList.add("pressed");
  updateLocks();
}
btnAccel.ontouchstart = e=>{e.preventDefault(); setMotor(1,btnAccel);};
btnRev.ontouchstart   = e=>{e.preventDefault(); setMotor(2,btnRev);};
btnBrake.ontouchstart = e=>{e.preventDefault(); setMotor(0,btnBrake);};
const handleRelease = ()=>{ if(!driveFast) setMotor(0); };
btnAccel.ontouchend = handleRelease;
btnRev.ontouchend   = handleRelease;

hazardBtn.onclick = ()=>{ hazardOn=!hazardOn; if(!hazardOn) setBtnStyle(hazardBtn,false); };
lowBtn.onclick = ()=>{ lowOn=!lowOn; setBtnStyle(lowBtn,lowOn,"#00838f","white","#00e5ff"); };
swDrive.onclick = ()=>{
  driveFast=!driveFast;
  swDrive.innerText="MODO: "+(driveFast?"RÁP":"LEN");
  setBtnStyle(swDrive,!driveFast,GREEN,"white","white");
};
cardanBtn.onclick = ()=>{
  if(motorSt!==0 || !isOnline) return;
  cardanOn=!cardanOn;
  cardanBtn.innerText="CARDÁN: "+(cardanOn?"ACOPLADO":"DESACOPL.");
  setBtnStyle(cardanBtn,cardanOn,GREEN,"white","white");
  updateLocks();
};
btnUp.onclick   = ()=>{ tolvaCmd='U'; tolvaMoving=true; setBtnStyle(btnUp,true,GREEN,"white","white"); updateLocks(); };
btnDown.onclick = ()=>{ tolvaCmd='D'; tolvaMoving=true; setBtnStyle(btnDown,true,GREEN,"white","white"); updateLocks(); };

function setConnState(online){
  if(online===isOnline) return;
  isOnline = online;
  if(online){ connStatus.innerText="ONLINE"; connStatus.style.color=GREEN; }
  else { connStatus.innerText="OFFLINE"; connStatus.style.color=RED; setMotor(0); }
  updateLocks();
}

setInterval(()=>{
  const url = `/c?m=${motorSt}&d=${Math.round(curAng)}&l=${lowOn?1:0}&h=${hazardOn?1:0}&c=${cardanOn?1:0}&t=${tolvaCmd}`;
  fetch(url).then(r=>r.text()).then(msg=>{
    tolvaCmd=' ';
    lastOkTime = Date.now();
    setConnState(true);
    // msg = "LISTO" | "SUBIENDO" | "BAJANDO"
    tolvaStatus.innerText = msg;
    if(msg==="SUBIENDO" || msg==="BAJANDO"){
      tolvaStatus.style.color = ORANGE;
      tolvaMoving = true;
    } else {
      tolvaStatus.style.color = "#888";
      if(tolvaMoving){
        setBtnStyle(btnUp,false);
        setBtnStyle(btnDown,false);
        tolvaMoving = false;
        updateLocks();
      }
    }
  }).catch(()=>{});
}, 100);

setInterval(()=>{
  if(Date.now() - lastOkTime > 500) setConnState(false);
}, 200);

function animate(){
  if(!isTouchWheel) tarAng *= 0.85;
  curAng += (tarAng - curAng) * 0.2;
  wheel.style.transform = `rotate(${curAng}deg)`;
  requestAnimationFrame(animate);
}
animate();
updateLocks();
</script>
</body></html>
)rawliteral";

// ============================================================
// HANDLER PRINCIPAL
// ============================================================
void handleControl() {
  lastCommandTime = millis();
  failsafeActive = false;

  int    nuevoMotorState = motorState;
  bool   nuevoCardan     = cardanAcoplado;
  char   tCmd            = ' ';

  if (server.hasArg("m")) nuevoMotorState = server.arg("m").toInt();
  if (server.hasArg("d")) d_visual        = server.arg("d").toFloat();
  if (server.hasArg("l")) lowLights       = (server.arg("l").toInt() == 1);
  if (server.hasArg("h")) hazard          = (server.arg("h").toInt() == 1);
  if (server.hasArg("c")) nuevoCardan     = (server.arg("c").toInt() == 1);
  if (server.hasArg("t")) {
    String s = server.arg("t");
    if (s.length() > 0) tCmd = s.charAt(0);
  }

  // --- Bloqueos cruzados (defensa en profundidad) ---
  // 1. Cardán solo cambia con motor detenido
  if (nuevoCardan != cardanAcoplado && motorState == 0) {
    cardanAcoplado = nuevoCardan;
  }

  // 2. Si cardán acoplado, motor de tracción bloqueado
  if (cardanAcoplado) nuevoMotorState = 0;

  motorState = nuevoMotorState;

  // 3. Comandos de tolva solo con cardán acoplado y motor detenido
  if ((tCmd == 'U' || tCmd == 'D') && cardanAcoplado && motorState == 0
      && tolvaEstado == T_LISTO) {
    digitalWrite(pinEnable, LOW);   // Energizar driver antes de mover
    delay(2);                        // Tiempo de activación del driver
    if (tCmd == 'U') {
      stepper.moveTo(PASOS_MAXIMOS); // Subir: avanzar hasta la posición máxima
      tolvaEstado = T_SUBIENDO;
    } else {
      stepper.moveTo(0);             // Bajar: regresar a posición de reposo
      tolvaEstado = T_BAJANDO;
    }
  }

  // --- Aplicar dirección al servo ---
  int servoPos;
  if (d_visual < 0) servoPos = map((int)d_visual, -360, 0, MAX_IZQ, OFFSET_RECTO);
  else              servoPos = map((int)d_visual, 0, 360, OFFSET_RECTO, MAX_DER);
  direccion.write(servoPos);

  // --- Aplicar PWM al motor de tracción ---
  if (motorState == 1)      { analogWrite(pinMotorA, 255); analogWrite(pinMotorB, 0); }
  else if (motorState == 2) { analogWrite(pinMotorA, 0);   analogWrite(pinMotorB, 255); }
  else                      { analogWrite(pinMotorA, 0);   analogWrite(pinMotorB, 0); }

  // --- Responder con estado de tolva ---
  const char* estado;
  switch (tolvaEstado) {
    case T_SUBIENDO: estado = "SUBIENDO"; break;
    case T_BAJANDO:  estado = "BAJANDO";  break;
    default:         estado = "LISTO";    break;
  }
  server.send(200, "text/plain", estado);
}

// ============================================================
// LUCES
// ============================================================
void updateLights() {
  // --- Luz de freno con timer (1500ms) ---
  if (motorState == 0 && lastMotorState != 0) {
    brakeStartTime = millis();
    brakeActive = true;
  }
  if (brakeActive && (millis() - brakeStartTime >= BRAKE_DURATION_MS)) {
    brakeActive = false;
  }
  lastMotorState = motorState;

  digitalWrite(pinBajas,   lowLights ? HIGH : LOW);
  digitalWrite(pinFreno,   brakeActive ? HIGH : LOW);
  digitalWrite(pinReversa, (motorState == 2) ? HIGH : LOW);

  // --- Blink global ---
  if (millis() - lastBlink > BLINK_PERIOD_MS) {
    lastBlink = millis();
    blinkState = !blinkState;
  }

  // --- Giros / Balizas ---
  if (hazard) {
    digitalWrite(pinGiroIzq, blinkState ? HIGH : LOW);
    digitalWrite(pinGiroDer, blinkState ? HIGH : LOW);
  } else {
    digitalWrite(pinGiroIzq, (d_visual < -45 && blinkState) ? HIGH : LOW);
    digitalWrite(pinGiroDer, (d_visual >  45 && blinkState) ? HIGH : LOW);
  }
}

// ============================================================
// FAILSAFE
// ============================================================
void checkFailsafe() {
  if (millis() - lastCommandTime > FAILSAFE_TIMEOUT_MS) {
    if (!failsafeActive) {
      failsafeActive = true;
      // Cortar motor de tracción
      motorState = 0;
      analogWrite(pinMotorA, 0);
      analogWrite(pinMotorB, 0);
      // Apagar luces (excepto balizas, siguen parpadeando)
      lowLights = false;
      // Detener tolva si estaba moviéndose
      stepper.stop();
      digitalWrite(pinEnable, HIGH);  // Desenergizar motor ante pérdida de señal
      // Servo queda en su última posición (no tocamos direccion.write())
    }
  }
}

// ============================================================
// TOLVA: detectar fin de movimiento
// ============================================================
void updateTolva() {
  stepper.run();
  if (tolvaEstado != T_LISTO && stepper.distanceToGo() == 0) {
    tolvaEstado = T_LISTO;
    digitalWrite(pinEnable, HIGH);  // Desenergizar motor al llegar al destino
  }
}

// ============================================================
// SETUP
// ============================================================
void setup() {
  Serial.begin(115200);

  // Servo
  direccion.setPeriodHertz(50);
  direccion.attach(pinServo, 500, 2400);
  direccion.write(OFFSET_RECTO);

  // Pines de salida
  pinMode(pinMotorA, OUTPUT);
  pinMode(pinMotorB, OUTPUT);
  pinMode(pinBajas, OUTPUT);
  pinMode(pinFreno, OUTPUT);
  pinMode(pinReversa, OUTPUT);
  pinMode(pinGiroIzq, OUTPUT);
  pinMode(pinGiroDer, OUTPUT);

  // Stepper
  pinMode(pinEnable, OUTPUT);
  digitalWrite(pinEnable, HIGH);  // Motor desactivado al arrancar (posición: ABAJO = 0)
  stepper.setMaxSpeed(STEPPER_VMAX);
  stepper.setAcceleration(STEPPER_ACEL);
  stepper.setCurrentPosition(0);  // 0 = tolva abajo (reposo), PASOS_MAXIMOS = arriba

  // WiFi AP
  WiFi.softAP(ssid, password);
  Serial.print("AP IP: "); Serial.println(WiFi.softAPIP());

  // Web server
  server.on("/", []() { server.send_P(200, "text/html", html); });
  server.on("/c", handleControl);
  server.begin();

  lastCommandTime = millis();
}

// ============================================================
// LOOP
// ============================================================
void loop() {
  server.handleClient();
  updateLights();
  updateTolva();
  checkFailsafe();
}
